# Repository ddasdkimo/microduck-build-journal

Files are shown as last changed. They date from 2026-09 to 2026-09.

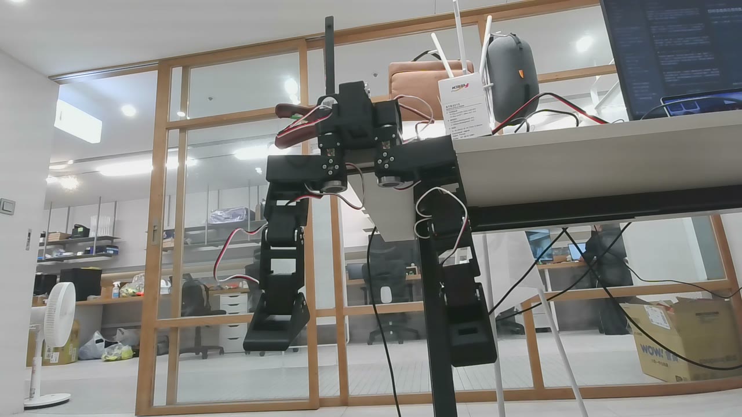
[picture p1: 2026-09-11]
public/assets/microduck-suspended-gait-demo-poster.jpg

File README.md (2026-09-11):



Live site: https://microduck.intemotech.com/
Hardware fork: https://github.com/ddasdkimo/Open_Duck_Mini/tree/codex/shin-unibody

# 小鴨製造所 / microduck-build-journal

公開建造日誌與重現指南。實作為 Open Duck Mini v2，起源故事來自建造者看到 Pollen Robotics Microduck 後循開源線索找到本專案。

## 本地與部署

```sh
npm ci
npm run dev
npm run build
npm run deploy
```

靜態輸出 `dist/client`，Cloudflare Workers Static Assets；網域 `microduck.intemotech.com`。需要自己的 Cloudflare 登入與網域存取權。帳號與授權值不寫入 repository。

公開資產已包含在 public；獨立 clone 不需要私人專案。`scripts/prepare_assets.py` 只供本地維護者從同層私人原始專案重新匯出 allowlist，CI 不執行此步驟。

## 維護

- 網站：app/ 下五個頁面與 globals.css。
- 讀者清單：scripts/reader-checklist.json，初始狀態全為未完成。
- 修改 STL 來源以硬體 fork 為主，未來以 Release 連結取代網站內快照；請連同 README、授權、geometry-check 一起保留。
- 每次新增日誌寫清楚日期、實測／CAD／待確認，不能把幾何驗證當成實物驗收。
- 不放入私人照片、連線位址、憑證、完整對話。

## Repo 分工

1. fork apirrone/Open_Duck_Mini 的 v2，維護硬體改版與重建程式；保留 upstream。
2. 本站單獨一個 microduck-build-journal repo，獨立版本與發布。
3. 硬體 Release 綁定修改來源 commit，網站文章連到該 Release。
4. 留言未啟用。可用 giscus 接公開 GitHub Discussions，或日後建置受控留言服務；目前沒有表單收集訪客資料。

## 上游

https://github.com/apirrone/Open_Duck_Mini
CAD 基準 b23317a485b3cec7d8417f352478778b3475173c。下載包保留 Apache-2.0。網站為非官方紀錄。

## 靜態導覽

站內頁面使用原生 `<a href>`，不要換成 `next/link`。目前 vinext 靜態輸出的 Link 切頁／prefetch 會拋出 TypeError 並攔截導覽。2026-09-08 已在正式站實際點擊首頁兩個 CTA，確認 /guide 與 /downloads 正常載入。

## 搜尋收錄與分享（2026-09-08）

- `lib/seo.ts` 定義每頁 canonical、Open Graph／Twitter 預覽與下載頁語言對應；預覽使用現有實際 CAD 圖。
- `public/sitemap.xml` 包含 12 個主要頁面；新增文章時需同步更新。lastmod 只在內容有實際修改時更新。
- `public/robots.txt` 允許抓取並指出 sitemap。文章本文預渲染為 HTML；Article JSON-LD 與可見內容一致。
- 3 篇技術筆記位於 `app/articles/`；英文下載頁在 `app/en/downloads/`。未公開私人相機照片，未增加追蹤腳本。
- 建置後執行 `python3 scripts/verify_public.py` 與 `python3 scripts/verify_seo.py`。
- Search Console：2026-09-08 經使用者確認帳號後，以 HTML meta 驗證 `https://microduck.intemotech.com/` 擁有權。已提交 sitemap，Google 顯示成功、探索到 12 個網頁。Google 搜尋生成式 AI 沿用 intemotech.com，實際控制值為「包含」；保持既有設定。這不表示 12 頁已建立索引或已被 AI 引用。請保留首頁 google-site-verification 標記。
- Google 官方現行指引： https://developers.google.com/search/docs/fundamentals/ai-optimization-guide 。不需要 llms.txt；正常收錄、可顯示摘要和 Search Console AI 控制才是重點。符合條件仍不保證收錄或引用。
- AI 控制與成效報表：https://support.google.com/webmasters/answer/16908024 、https://support.google.com/webmasters/answer/16984139 。2026-09-08 查閱。

## GitHub 自動部署

Push 到 `main` 後，GitHub Actions 會安裝鎖定依賴、檢查 TypeScript、建置靜態頁、檢查連結／SEO，再部署到 microduck.intemotech.com。PR 只跑檢查，不發布。部署使用 repo Secret `CLOUDFLARE_API_TOKEN`；不要把 Token 寫進程式或設定檔。

`public/` 內的下載與圖片快照已納入 Git，CI 不需要私人父專案。`prepare:assets` 僅供原建造工作區維護者同步資產。

## 留言功能

技術文章、建造日誌與下載頁提供匿名留言，先審核再公開。D1儲存與管理方式見 [docs/comments.md](docs/comments.md)。Cloudflare 靜態資產搭配 `/api/*` 留言 Worker；管理頁 `/moderation.html`。

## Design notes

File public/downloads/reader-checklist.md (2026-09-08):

# 你的 Open Duck Mini v2 建造清單
所有項目從未完成開始，請依自己的實測填寫。

## 版本與材料
先核對自己的零件；此清單從零開始。

- [ ] 確認採用 Open Duck Mini v2
  記錄上游版本；本站 CAD 基於 b23317a485b3cec7d8417f352478778b3475173c。

- [ ] 點收舵機與電控材料
  本次採 7.4V STS3215 系列，14 顆關節＋1 顆備品；依官方 BOM 核對電源與版本。

- [ ] 批次 0 小件試配
  先印 leg_spacer、roll_motor_top、roll_motor_bottom；確認嵌件、軸承與舵機配合。

- [ ] 核對熱熔嵌件尺寸與孔位
  本次 spacer 使用 M3、外徑 4.5 mm、長 5 mm，每件四顆。較淺的孔另量深度；Ø6 大孔不是嵌件孔。

## 舵機驗收
電性、位置與人耳異音分開記錄，不以沒有回報異常取代檢查。

- [ ] 逐顆記錄電壓、溫度、位置與電流
  單顆測試並編號，保留原始量測；先空載，再裝盤複測。

- [ ] 逐顆確認運轉聲音
  明確記錄有無異音；未聽測的維持未完成。

- [ ] 設定 ID、歸零並安裝舵盤
  右腿 10–14、左腿 20–24、頭頸 30–33；備品保留 ID 1。方向以官方設定表與組裝圖為準。

- [ ] 裝盤後複測並排除機械夾緊
  中心螺絲不能使舵機受阻；記錄調整前後的電流與到位結果。

## 右腿組裝
左右薄板不同且有方向性。一體件 v1／v2 為實驗改版，尚未實物驗證。

- [ ] 點收批次 1 列印件
  含 trunk_bottom 共 13 PLA＋1 TPU；件數見下方表格。

- [ ] 組裝右腳與踝舵機 ID 14
  依官方圖確認驅動板面朝 foot_top，PLA／TPU 腳底配合。

- [ ] 試配並組裝小腿
  兩款薄板各一片＋spacer；先接踝線並穿過指定薄板開口，確認方向再鎖緊。

- [ ] 試配並組裝大腿
  同樣用兩款薄板＋spacer，連接 ID 12 與 ID 13；髖 pitch 朝向依官方零位。

- [ ] 組裝右髖座並確認軸承配合
  ID 10 下方主動舵盤接 roll_motor_top；top 與 bottom 支承 ID 11。bottom 凸軸接 6804ZZ 內圈。

- [ ] 完成靜態干涉與線路檢查
  確認解除扭力後輕移關節；不強推止點，檢查夾線、卡點、鬆動與裂損。

## 電源與電控
本站目前沒有驗證完成的通用電池接線方案。依實際板型與官方資料核對。

- [ ] 確認電池、BMS、充電器匹配與接線
  辨識每個板子的實際端子、極性與額定規格，不能只按相似外觀照接。

- [ ] 記錄電池與穩壓輸出量測
  接入主控前量測並確認極性與額定輸出，保留數值。

- [ ] 準備 Pi、驅動與推論環境
  依官方 Runtime 說明安裝；記錄版本並確認 Adapter 能辨識。

- [ ] 固定機構後進行單腿小幅測試
  逐顆確認 ID 與方向，依實測設定供電限制；本站尚未完成此階段。

## 全機與驗證
後續流程為規劃，本站尚未完成全機行走驗收。

- [ ] 完成左腿與頭頸總成
  左側使用 left_roll_to_pitch；依官方圖核對舵機 ID、方向與線材。

- [ ] 全機接線、校正與逐關節測試
  先核對回應與方向，再進行姿態校正，記錄版本及結果。

- [ ] 完成站立與行走驗收
  依官方流程，保留可重現的參數、環境與測試結果。

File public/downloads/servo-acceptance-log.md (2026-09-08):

# STS3215 到貨驗收紀錄

本次建造的舵機驗收紀錄；量測為個別實測值。判定:型號對、電壓 6.5–8.5V、溫度 <45°C、±60° 誤差 <3°、空載電流 <600 mA、無異音。

| # | 日期 | 電壓 | 溫度 前/後 | ±60° 誤差 | 最大電流 | 異音 | 電性／位置判定 | 設 ID | 舵盤 | 備註 |
|---|---|---|---|---|---|---|---|---|---|---|
| 1 | 09-06 | 6.9 V(電池) | 30 / 30 | 0.1° | 280 mA | 無 | 通過 | 10 右髖yaw | 已裝 | 複測 ±90° 到位,221–312 mA,34°C |
| 2 | 09-07 | 7.6 V(電源供應器) | 26 / 26 | 0.2° | 351 mA | 無 | 通過 | 11 右髖roll | 已裝 | 裝盤後 ±90° 到位,130–364 mA,29°C |
| 3 | 09-07 | 7.6 V(電源供應器) | 26 / 27 | 0.2°(首測 +60 只到 56.7 為起點 −179° 行程太長的時序誤判,重測全到位) | 110 mA | 待確認 | 通過 | 12 右髖pitch | 已裝 | 電流偏低 84–110 mA,屬正常變異 |
| 4 | 09-07 | 7.6 V(電源供應器) | 26 / 27 | 0.1° | 286 mA | 待確認 | 通過 | 13 右膝 | 已裝 | |
| 5 | 09-07 | 7.6 V(電源供應器) | 26 / 26 | 0.2° | 130 mA | 待確認 | 通過 | 14 右踝 | 已裝 | |
| 6 | 09-07 | 7.6 V(電源供應器) | 26 / 26 | 0.1° | 110 mA | 待確認 | 通過 | 20 左髖yaw | 已裝 | |
| 7 | 09-07 | 7.6 V(電源供應器) | 26 / 26 | 0.1° | 130 mA | 待確認 | 通過 | 21 左髖roll | 已裝 | |
| 8 | 09-07 | 7.6 V(電源供應器) | 25 / 25 | 0.1° | 292 mA | 待確認 | 通過 | 22 左髖pitch | 已裝 | |
| 9 | 09-07 | 7.6 V(電源供應器) | 26 / 26 | 0.1° | 117 mA | 待確認 | 通過 | 23 左膝 | 已裝 | |
| 10 | 09-07 | 7.7 V(電源供應器) | 26 / 26 | 0.1° | 260 mA | 待確認 | 通過 | 24 左踝 | 已裝 | |
| 11 | 09-07 | 7.6 V(電源供應器) | 27 / 28 | 0.1° | 273 mA | 待確認 | 通過 | 30 頸pitch | 已裝 | |
| 12 | 09-07 | 7.6 V(電源供應器) | 26 / 26 | 0.1° | 318 mA | 待確認 | 通過 | 31 頭pitch | 已裝 | |
| 13 | 09-07 | 7.6 V(電源供應器) | 28 / 28 | 0.1° | 260 mA | 待確認 | 通過 | 32 頭yaw | 已裝 | 連續取樣最大 332 mA、平均 39 mA、無尖峰 |
| 14 | 09-07 | 7.6 V(電源供應器) | 27 / 27 | 0.1° | 266 mA | 待確認 | 通過 | 33 頭roll | 已裝 | 連續取樣最大 338 mA、平均 37 mA、無尖峰 |
| 15 | 09-07 | 7.6 V(電源供應器) | 26 / 26 | 0.1° | 260 mA | 待確認 | 通過 | 備品,保持 ID 1 | 不裝 | |

**結論(09-07,09-07 晚更正)**:15 顆電性與位置全部通過,0 顆退換;14 顆已設 ID 並裝舵盤;ID 24、31 螺絲過緊已修正。**異音欄:第 1、2 顆為 建造者 明確回報,第 3–14 顆是他未回報異音即接續裝盤的推定,第 15 顆未確認**,需 建造者 一次確認後才算全結案。

2026-09-07 Codex 接手：依同日交接確認，將第 3–14 顆異音欄由推定「無」改為「待確認」，保留所有量測數據。ID 10 沒有轉動受阻。

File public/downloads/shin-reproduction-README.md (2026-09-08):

# 小腿一體件重現包

上游：apirrone/Open_Duck_Mini，commit b23317a485b3cec7d8417f352478778b3475173c。
本包僅含右小腿所需三個 CAD 網格、URDF、重建程式與 Apache-2.0 授權。CAD 網格單位為公尺，腳本依 URDF 裝配後轉為毫米；不可再額外乘 1000。

修改日期 2026-09-08：v1 合併兩片薄板＋spacer，spacer 兩端各延伸 0.25mm；v2 補滿中央固定孔與沉孔。兩版均未完成實物裝入與列印驗證。

## 重建（Python 3.11）

```sh
python3.11 -m venv .venv
.venv/bin/python -m pip install -r requirements.txt
.venv/bin/python sim/print/build_shin_unibody.py
.venv/bin/python sim/print/build_shin_unibody_filled.py
```

輸出位於 designs/right-shin-unibody-v1 與 v2。STL、PNG 與 geometry-check.json 一起生成。圖形字型只影響圖片外觀，不影響 STL。

build_assembly_data.py 在本包中僅提供 tf、ROOT、SOURCE，不能單独執行完整全機生成（其餘全機網格請從上游取得）。

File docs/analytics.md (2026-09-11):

# Website analytics

Cloudflare Web Analytics enabled 2026-09-11 for microduck.intemotech.com.
Site tag: 465b0e0d5c3f4e0c9823733ddb08243a.

The public collection token in public/web-analytics.js is not an API credential.
The shared layout and standalone assembly/checklist pages load this module.
It only runs on the production hostname; local previews and moderation are excluded.
The asset preparation script preserves the integration when exporting guides again.

Dashboard: https://dash.cloudflare.com/ed55dc446113891dee896596886735dd/web-analytics/overview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

Use page views and visits for browsing trends, not Worker asset request counts.
Collection starts after installation, and reporting can take several minutes.
Browser blockers may prevent collection; visits are not a count of unique people.

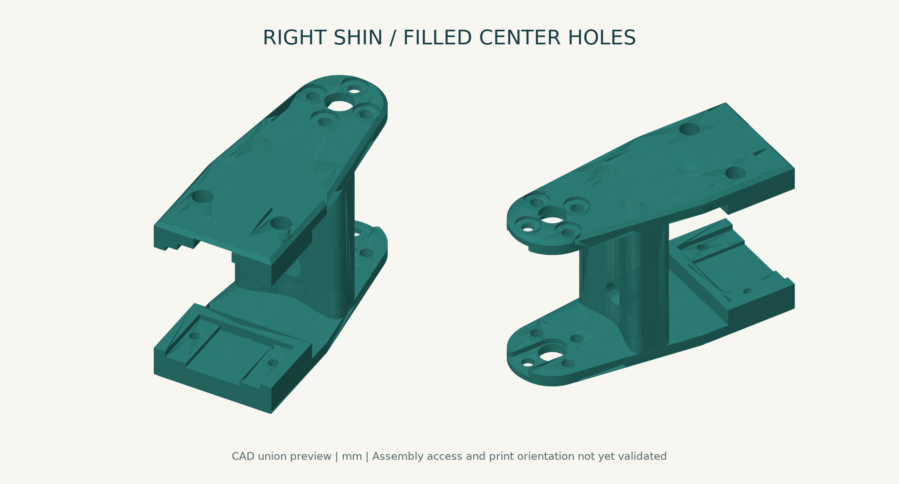
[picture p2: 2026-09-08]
public/assets/shin-v2.png

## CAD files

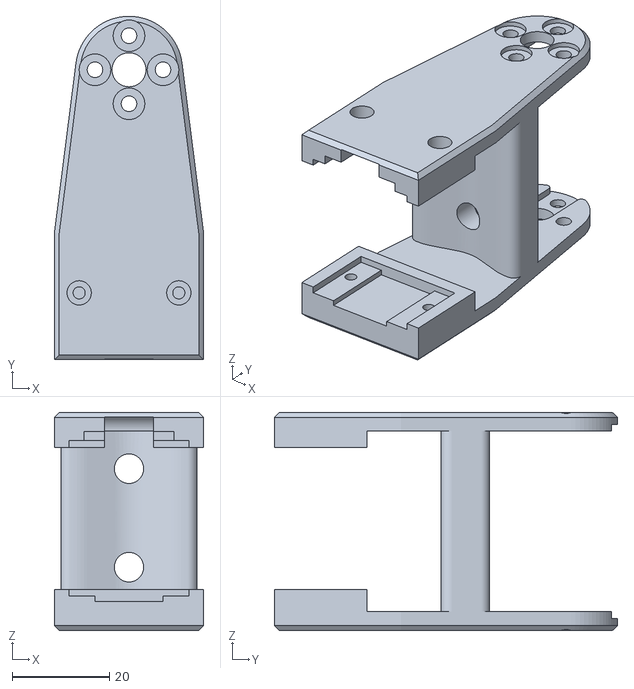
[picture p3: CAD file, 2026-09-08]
public/downloads/right-shin-v2.stl
30.7 x 70.6 x 44.8

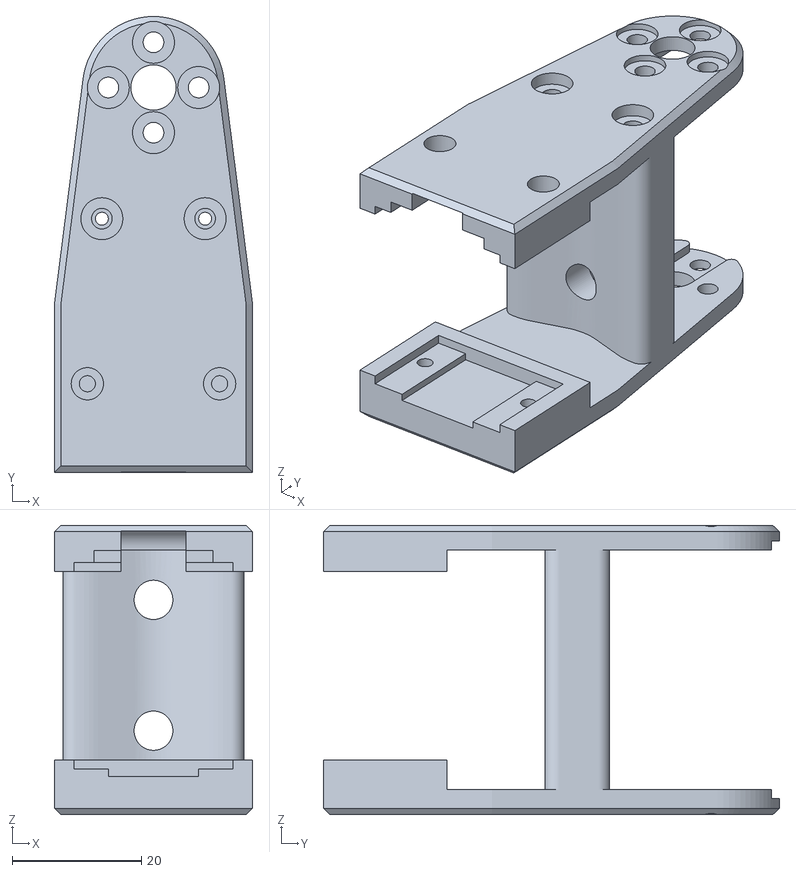
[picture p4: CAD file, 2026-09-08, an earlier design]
public/downloads/right-shin-v1.stl
30.7 x 70.6 x 44.8

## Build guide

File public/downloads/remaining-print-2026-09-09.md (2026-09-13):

# 2026-09-09 剩餘列印包：右腿完成之後

此包是本站當次建造進度的續印範例，不是全機完整套件。31 件：30 PLA、1 TPU。每個 STL 印一次，兩件一體框架已各存一份。

前提：右腿及 trunk_bottom 已完成；庫存已有 roll_motor_bottom 1 件、roll_motor_top 2 件，左腿各取一件，剩一件 top 備用。身體與頭部尚未印。若你的進度不同，請依上游完整列印指南重新點收，不能直接把本包當成全部用量。

左腿兩組薄板＋spacer（6件）改為 right-shin-unibody-v2 中央孔補滿的一體框架（2件），分別用於左大腿與左小腿。CAD 四段腿的來源網格與相對配置一致，沒有鏡射。左腿實物裝入、走線與強度仍需驗證；建議先印一件試配，再印第二件。

分組：左腿 7、腿部外側護蓋 2、身體外殼 6、頸部 5、頭部 11。`left_cache`／`right_cache` 是左右大腿護蓋。PLA 15% 填充，TPU 40%（上游設定）；一體版尚無經驗證的切片設定，請確認擺放、支撐與貼床。毫米單位，尚未切片。

來源：Open Duck Mini v2，上游基準 b23317a485b3cec7d8417f352478778b3475173c。
https://github.com/apirrone/Open_Duck_Mini
改版與重建：https://microduck.intemotech.com/articles/one-piece-shin
授權：附 LICENSE-Open-Duck-Mini.txt；一體件為本站衍生修改。

## 逐件清單

- [ ] 01_左腿/PLA_15%/foot_bottom_pla__01_of_01.stl
- [ ] 01_左腿/PLA_15%/foot_side__01_of_01.stl
- [ ] 01_左腿/PLA_15%/foot_top__01_of_01.stl
- [ ] 01_左腿/PLA_15%/left_roll_to_pitch__01_of_01.stl
- [ ] 01_左腿/PLA_15%/leg-unibody-v2-filled__01_of_02__左大腿.stl
- [ ] 01_左腿/PLA_15%/leg-unibody-v2-filled__02_of_02__左小腿.stl
- [ ] 01_左腿/TPU_40%/foot_bottom_tpu__01_of_01.stl
- [ ] 02_身體外殼/PLA_15%/battery_pack_lid__01_of_01.stl
- [ ] 02_身體外殼/PLA_15%/body_back__01_of_01.stl
- [ ] 02_身體外殼/PLA_15%/body_front__01_of_01.stl
- [ ] 02_身體外殼/PLA_15%/body_middle_bottom__01_of_01.stl
- [ ] 02_身體外殼/PLA_15%/body_middle_top__01_of_01.stl
- [ ] 02_腿部外側護蓋/PLA_15%/left_cache__01_of_01.stl（左大腿外側護蓋）
- [ ] 02_腿部外側護蓋/PLA_15%/right_cache__01_of_01.stl（右大腿外側護蓋）
- [ ] 02_身體外殼/PLA_15%/trunk_top__01_of_01.stl
- [ ] 03_頸部/PLA_15%/head_pitch_to_yaw__01_of_01.stl
- [ ] 03_頸部/PLA_15%/head_roll_mount__01_of_01.stl
- [ ] 03_頸部/PLA_15%/head_yaw_to_roll__01_of_01.stl
- [ ] 03_頸部/PLA_15%/neck_left_sheet__01_of_01.stl
- [ ] 03_頸部/PLA_15%/neck_right_sheet__01_of_01.stl
- [ ] 04_頭部/PLA_15%/bulb__01_of_01.stl
- [ ] 04_頭部/PLA_15%/flash_light_module__01_of_01.stl
- [ ] 04_頭部/PLA_15%/flash_reflector_interface__01_of_01.stl
- [ ] 04_頭部/PLA_15%/head__01_of_01.stl
- [ ] 04_頭部/PLA_15%/head_bot_sheet__01_of_01.stl
- [ ] 04_頭部/PLA_15%/left_antenna_holder__01_of_01.stl
- [ ] 04_頭部/PLA_15%/left_eye__01_of_01.stl
- [ ] 04_頭部/PLA_15%/right_antenna_holder__01_of_01.stl
- [ ] 04_頭部/PLA_15%/right_eye__01_of_01.stl
- [ ] 04_頭部/PLA_15%/speaker_interface__01_of_01.stl
- [ ] 04_頭部/PLA_15%/speaker_stand__01_of_01.stl

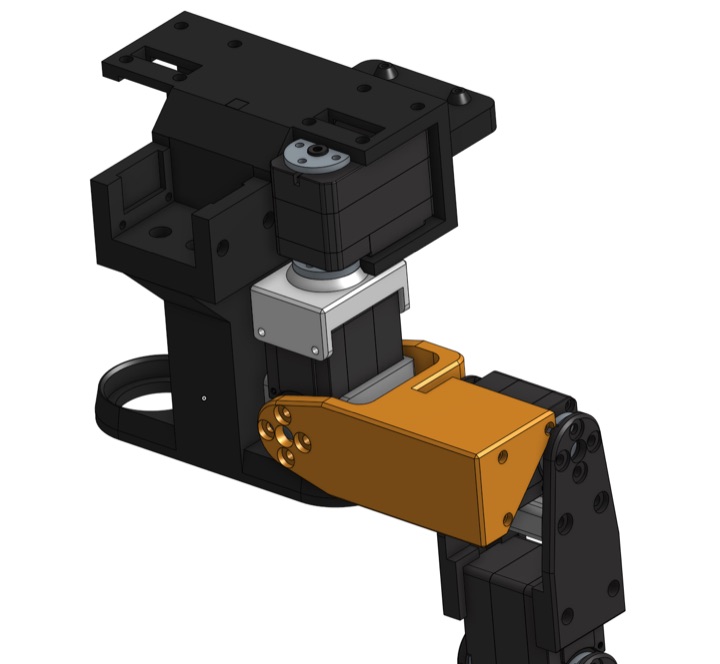
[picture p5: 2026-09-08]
public/assets/assembly/6aeb874f9aaa6d10.jpg

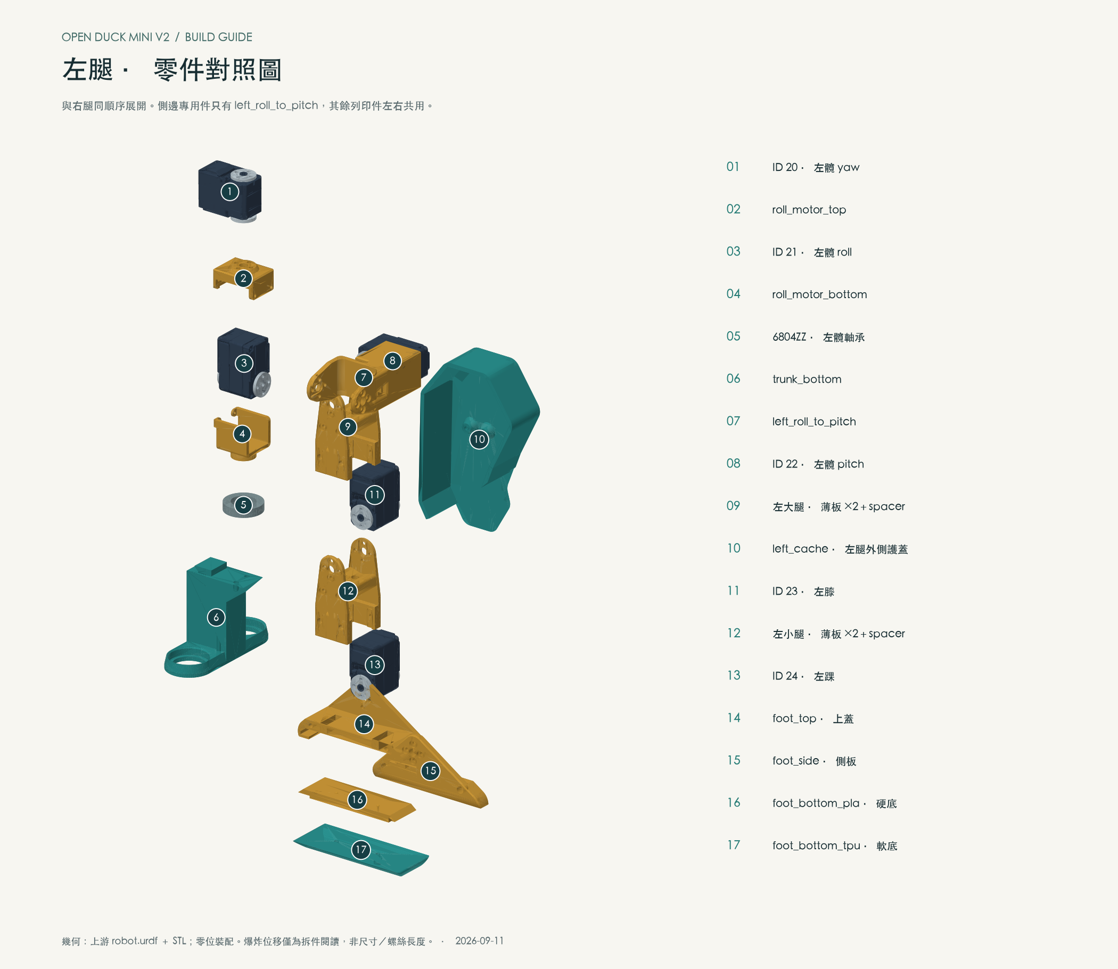
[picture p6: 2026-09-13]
public/assets/assembly/1f051458ebe270c8.png

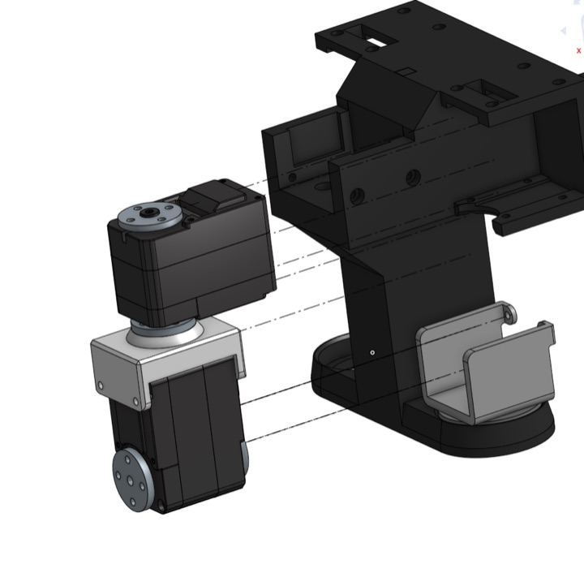
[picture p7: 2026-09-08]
public/assets/assembly/0f6bf0b633ddff4c.jpg

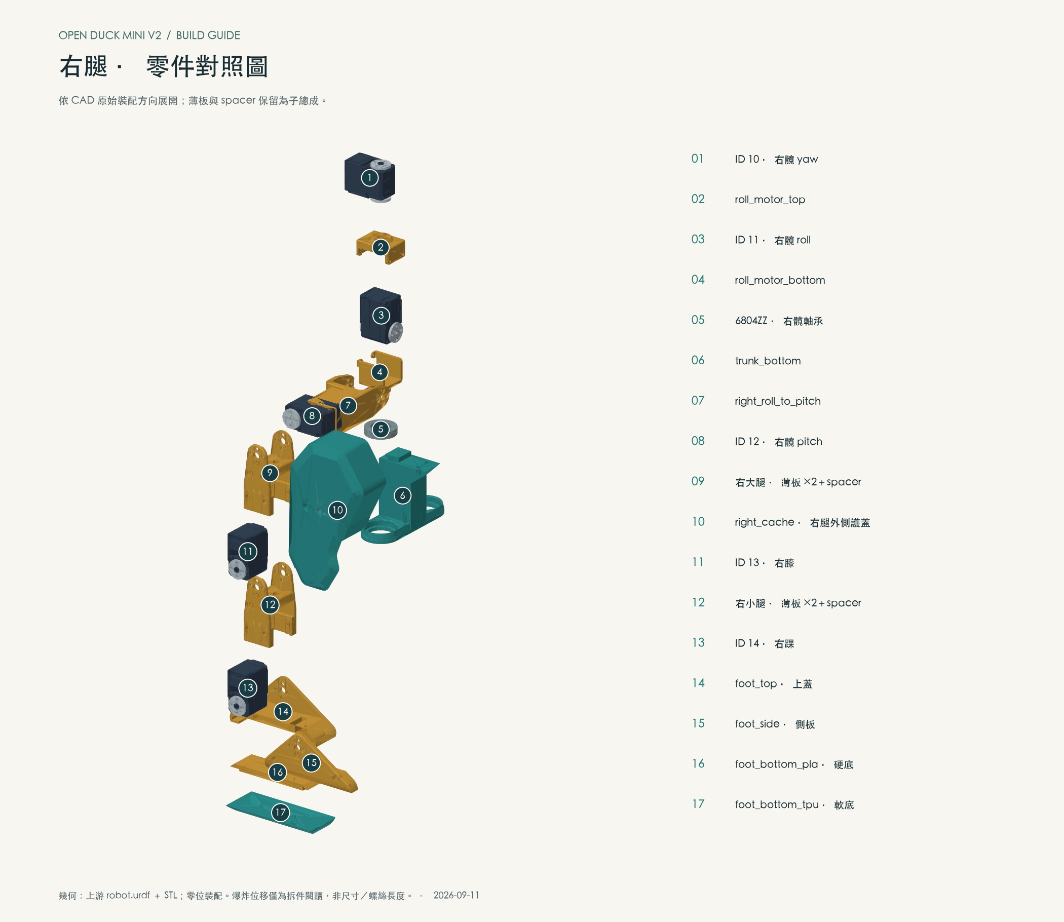
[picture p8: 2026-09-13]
public/assets/assembly/0a3c57eeff239386.png

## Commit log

2026-09-08 Build public Open Duck Mini journal and reproduction guide
    [right-shin-v1.stl, right-shin-v2.stl]
2026-09-09 Add pre-assembly cable routing guide and part-specific wiring reminders
2026-09-09 Document unibody substitutions and publish remaining print package
2026-09-10 Add the left leg to the assembly viewer
    The viewer only covered the right hip, right leg and the full robot, so the
    left leg could only be seen as one rigid block in the full scene. Build a left
    scene with the same sixteen steps as the right so both legs can be worked
    through part by part.
    Only left_roll_to_pitch and the second 6804ZZ differ per side; every other
    printed part is shared. Exploded offsets mirror in y. Pre-wiring notes say the
    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
2026-09-11 Add CAD torso exploded scene and downloadable diagrams
2026-09-11 Label each torso servo with its configured ID
2026-09-13 Add neck assembly and classify leg covers
2026-09-13 Complete body and head assembly guidance
2026-09-14 Add electronics wiring and installation guide
2026-09-15 Add 2S battery wiring diagram
